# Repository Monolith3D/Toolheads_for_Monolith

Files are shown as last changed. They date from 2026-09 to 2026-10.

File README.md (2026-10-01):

# Toolheads for Monolith

Belt clamps, alignment helpers, and design guidance for adapting toolheads to the Monolith Gantry.

## Compatible toolheads

Each project provides its own files, build instructions, updates, and support.

- [A4T](https://github.com/Armchair-Heavy-Industries/A4T)
- [Angry Tool Head](https://github.com/Shamoon78/Angry_Tool_Head)
- [Archetype](https://github.com/Armchair-Heavy-Industries/Archetype)
- [Banantis](https://github.com/jakub874/Banantis)
- [Burninator](https://github.com/The-Duke-96/Burninator)
- [DK's Monolith Toolhead](https://github.com/Kizime123/DKs-Monolith-Toolhead)
- [Dreadnaught Toolhead](https://github.com/Thescarecow/Dreadnaught-Toolhead)
- [FiberStream Toolhead](https://www.printables.com/model/1219174-fiberstream-toolhead)
- [Gustav Railway Toolhead](https://github.com/RCI-Nicket/Gustav-Railway-Toolhead)
- [Microwaved Bowden Toolhead](https://github.com/micreathonn/Microwaved-Bowden-Toolhead)
- [RX Toolhead](https://makerworld.com/en/models/2816460-rx-toolhead-v5-using-bambu-h2s-a1-gear-hotend)
- [Sphinx Toolhead](https://github.com/riley-github/Sphinx-Toolhead)
- [Stormbreaker Toolhead](https://github.com/Gr33n5murf/Stormbreaker-Toolhead)
- [Takeoff Toolhead](https://github.com/Kizime123/Takeoff-Toolhead)
- [Trinity Toolhead](https://github.com/WV-design/Trinity-toolhead/)
- [Trinicorn SLM Toolhead](https://github.com/Martin-Ivanc/Trinicorn-Toolhead/)
- [UAP](https://www.printables.com/model/1353685-uap-v6)
- [Xol Toolhead](https://github.com/Armchair-Heavy-Industries/Xol-Toolhead)

## Belt clamps

The [Monolith belt clamp](Monolith_Belt_Clamp/) is a reference design for belt retention and easier adaptation to Monolith's belt path, available in milled and SLM variants.

### LDO milled belt clamp vendors

- [West3D](https://west3d.com/products/monolith-cnc-belt-clamp-by-ldo-motors) (US)
- [MyRigs](https://myrigs3d.com/fr/products/ldo-monolith-cnc-belt-clamp) (EU)
- [Zen3D](https://shop.zen3d.eu/monolith-cnc-belt-clamp) (EU)

### SLM belt clamp vendors

- [DK Supply](https://diodekingsupply.com/products/monolith-slm-belt-clip) (US)
- [3DKATTEN](https://3dkatten.se/products/monolith-slm-belt-clamp) (EU)
- [Pjotr3DShop](https://pjotr3dshop.com/products/monolith-slm-belt-clamp-aluminium) (EU)

## Belt alignment helpers

[Printable helpers](Belt_Alignment_Helpers/) and installation instructions for checking vertical belt spacing at the toolhead.

## Design guidelines

[Design guidelines](Design_Guidelines/) and integration CAD for adapting toolheads to Monolith.

## User Mods

Community-made additions and adaptations to help toolheads work with the Monolith Gantry.
Geometry and designs from other projects, including their derivatives, remain subject to their original licenses.

[Existing User Mods](UserMods/#existing-user-mods)

## Support

> [!NOTE]
> **If you have questions or want to stay more up-to-date with Monolith, consider joining the dedicated Discord server.**
>
> Join the Discord (https://discord.gg/monolith3d)
>
> **If you would like to see more of this and other projects in the future, consider supporting Monolith on Patreon.**
>
> Support Monolith on Patreon (https://www.patreon.com/monolith3d)

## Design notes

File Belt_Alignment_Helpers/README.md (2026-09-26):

# Belt Alignment Helpers

Check vertical belt spacing at the toolhead. Choose the helper that matches your belt width.

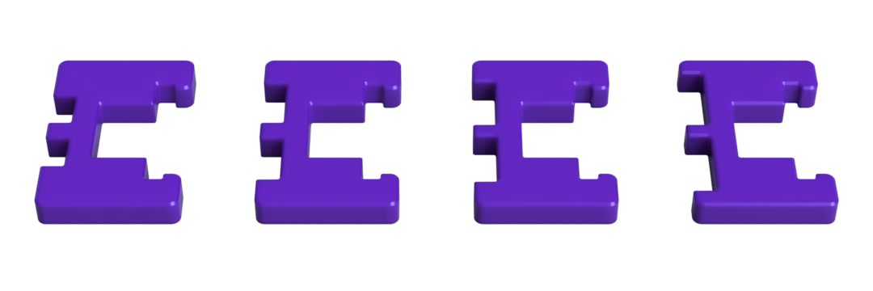
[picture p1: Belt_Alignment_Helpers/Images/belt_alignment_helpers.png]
Belt alignment helpers


STLs: [6 mm](STLs/6mm_belt_offset_helper.stl) · [9 mm](STLs/9mm_belt_offset_helper.stl) · [10 mm](STLs/10mm_belt_offset_helper.stl) · [12 mm](STLs/12mm_belt_offset_helper.stl)

[Download the STEP assembly](CAD/Belt_offset_helpers.step)

## How to use

Slide the helper between the X-rail and the belts, then rotate it into position to check the spacing. Check both sides of the toolhead.

Watch the installation video on YouTube (https://youtube.com/shorts/-358SNaWWXc)

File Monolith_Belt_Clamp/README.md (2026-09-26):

# Monolith Belt Clamp

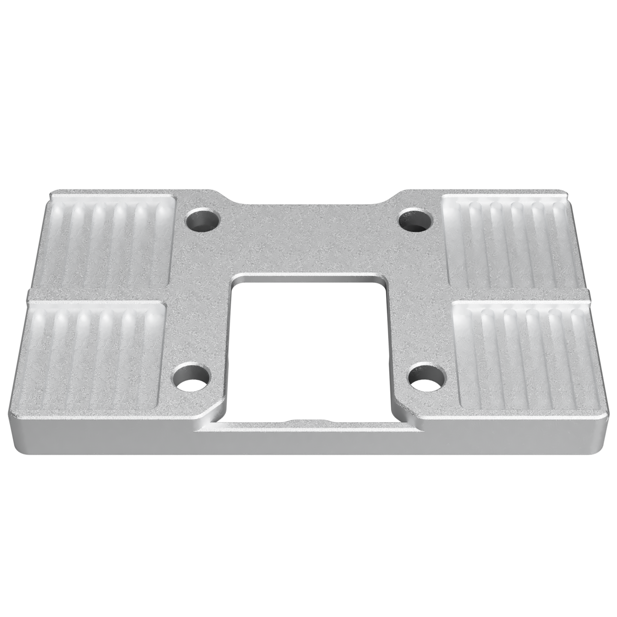
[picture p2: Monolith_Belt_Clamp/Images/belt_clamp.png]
Monolith milled belt clamp


A metal belt clamp for adapting toolheads to Monolith's flipped belt path, including toolheads with printed carriages.

The belt path runs one belt thickness from the MGN12H carriage, leaving room for a thin clamp around it.

## Design goals

- Single-piece, lightweight, and compact.
- At least six teeth engaged, as recommended by Gates.
- A straight loaded belt section without tight bends.
- Preserve standard 250, 300, and 350 mm X travels.
- Accommodate belts up to 12 mm wide without vertical restriction.
- Clip onto the carriage without screws during toolhead assembly.
- Keep excess belt outside, with easy slack removal using two partially tightened screws.

## Variants

Both versions have the same fit and function and are interchangeable in existing toolhead designs. Prefer milled when getting a new clamp, but there's no reason to replace an SLM clap that already works well.

- [Milled](Milled/): Improved version with more consistent manufacturing. Recommended over SLM.
- [SLM](SLM/): Quality varies by supplier and batch, and the geometry makes manufacturing defects difficult to correct through post-processing.

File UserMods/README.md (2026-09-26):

# User Mods

Community-made additions and adaptations to help toolheads work with the Monolith Gantry.

Geometry and designs from other projects, including their derivatives, remain subject to their original licenses.

Use the folder structure `username/usermod_name` for new user mods.

## Existing User Mods

No user mods have been added yet. The rows below are examples for new submissions.

| Mod | Author | What it does |
| --- | --- | --- |
| usermod_name | username | Briefly describe what the mod adds, adapts, or changes. |
|  | your name here :) |  |

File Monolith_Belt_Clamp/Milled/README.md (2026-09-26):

# Milled Belt Clamp

The milled belt clamp, co-developed with **@dderg**.

## CAD

[STEP file](CAD/Monolith_Milled_Belt_Clamp.step)

## LDO milled belt clamp vendors

- [West3D](https://west3d.com/products/monolith-cnc-belt-clamp-by-ldo-motors) (US)
- [MyRigs](https://myrigs3d.com/fr/products/ldo-monolith-cnc-belt-clamp) (EU)
- [Zen3D](https://shop.zen3d.eu/monolith-cnc-belt-clamp) (EU)

The LDO version is black-anodized aluminum.

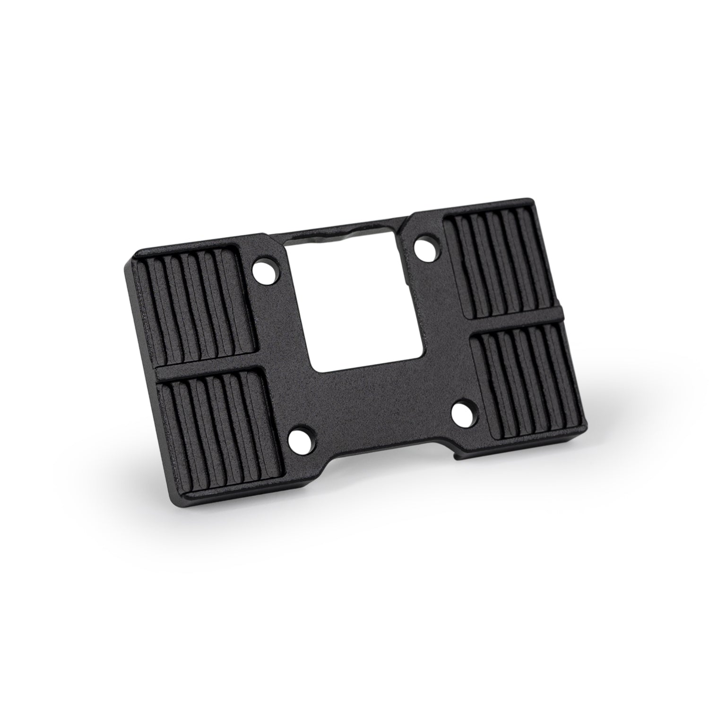
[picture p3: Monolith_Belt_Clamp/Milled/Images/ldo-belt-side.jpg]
LDO milled belt clamp


## Development

Developed from the A-type SLM version. Early prototypes made by @dderg introduced a heatbreak cutout, a flat front, and longer AirTAC carriage compatibility.

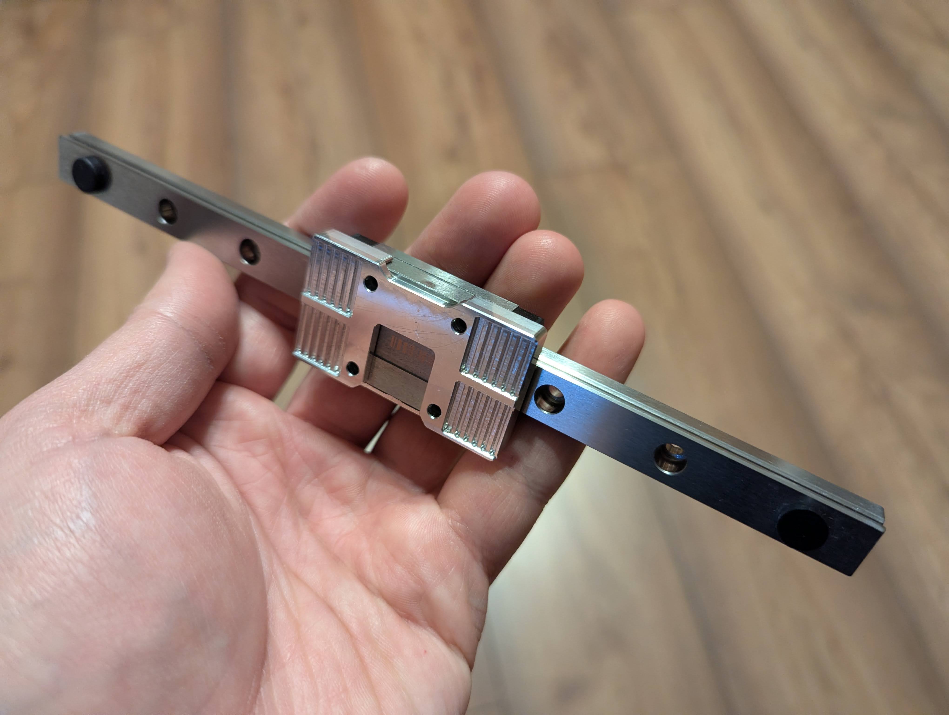
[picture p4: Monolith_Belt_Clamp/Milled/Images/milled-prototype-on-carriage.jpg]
Earlier milled prototype on a carriage


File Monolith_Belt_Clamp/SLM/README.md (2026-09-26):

# SLM Belt Clamp

The SLM metal belt clamp for Monolith's flipped belt path.
## CAD

- [STEP file](CAD/Monolith_SLM_Belt_Clamp.step)
- [STL file](STL/Monolith_SLM_Belt_Clamp.stl)

## SLM belt clamp vendors

- [DK Supply](https://diodekingsupply.com/products/monolith-slm-belt-clip) (US)
- [3DKATTEN](https://3dkatten.se/products/monolith-slm-belt-clamp) (EU)
- [Pjotr3DShop](https://pjotr3dshop.com/products/monolith-slm-belt-clamp-aluminium) (EU)

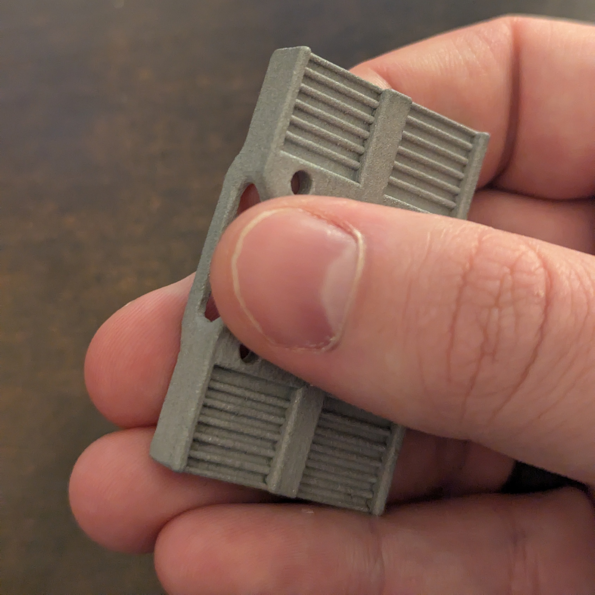
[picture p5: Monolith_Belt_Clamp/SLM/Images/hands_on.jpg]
SLM belt clamp


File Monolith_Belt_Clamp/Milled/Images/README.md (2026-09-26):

# LDO Belt Clamp Photos

| Image | Image |
| --- | --- |
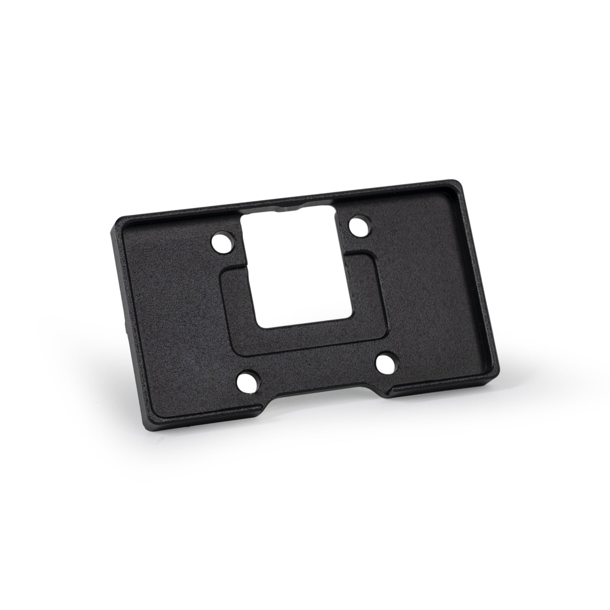
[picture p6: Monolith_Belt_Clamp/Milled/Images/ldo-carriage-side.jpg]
LDO belt clamp carriage-facing side
| [LDO belt clamp belt-facing side<br>Belt-facing side](ldo-belt-side.jpg) | [<br>Carriage-facing side](ldo-carriage-side.jpg) |
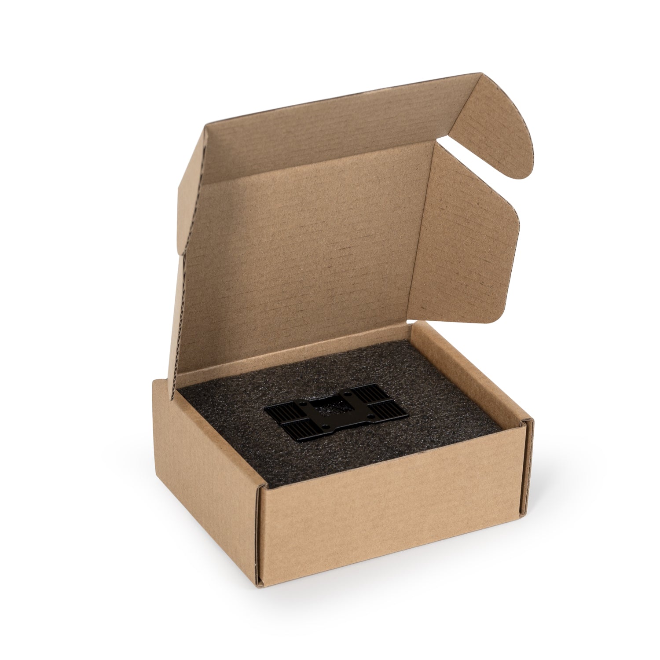
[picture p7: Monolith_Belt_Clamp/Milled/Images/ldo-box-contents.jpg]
LDO belt clamp in its open box
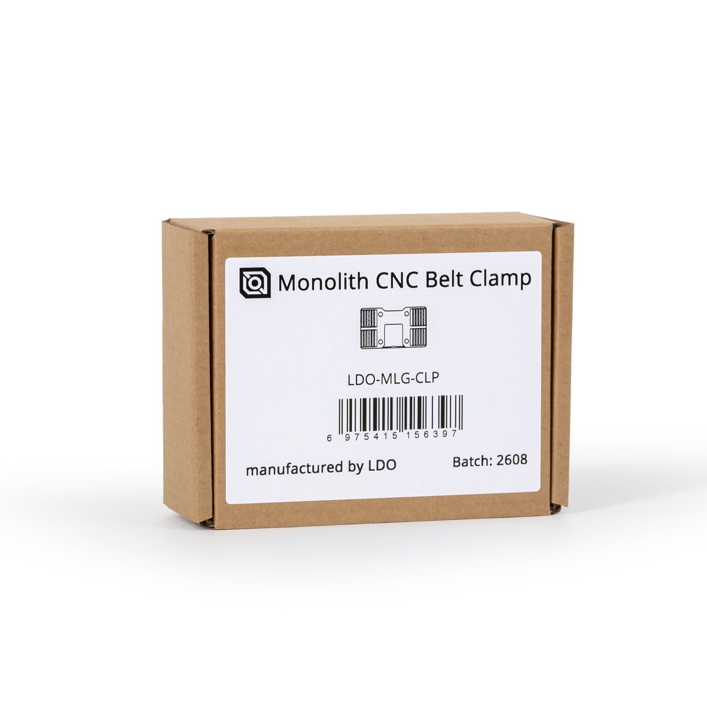
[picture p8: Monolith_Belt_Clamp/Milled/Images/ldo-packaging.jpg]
LDO belt clamp package label
| [<br>Box contents](ldo-box-contents.jpg) | [<br>Packaging](ldo-packaging.jpg) |

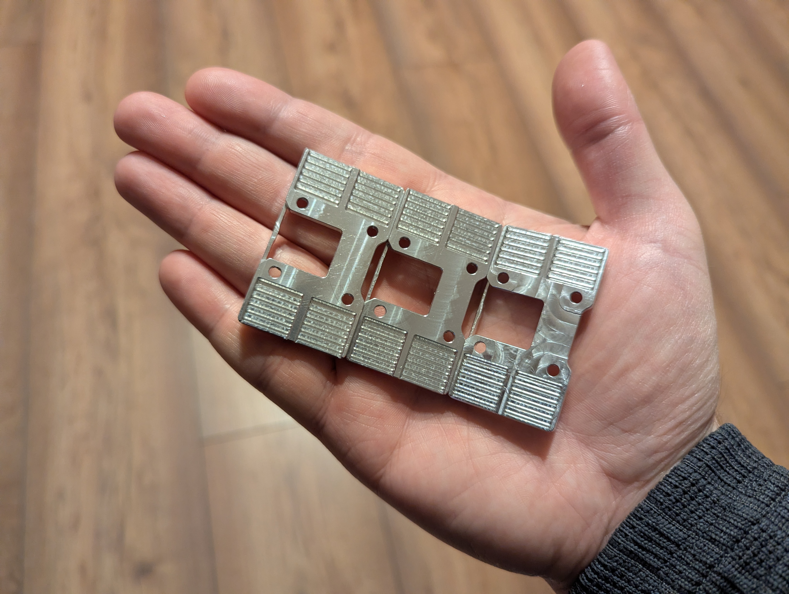
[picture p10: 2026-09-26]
Monolith_Belt_Clamp/Milled/Images/milled-prototype-iterations.jpg

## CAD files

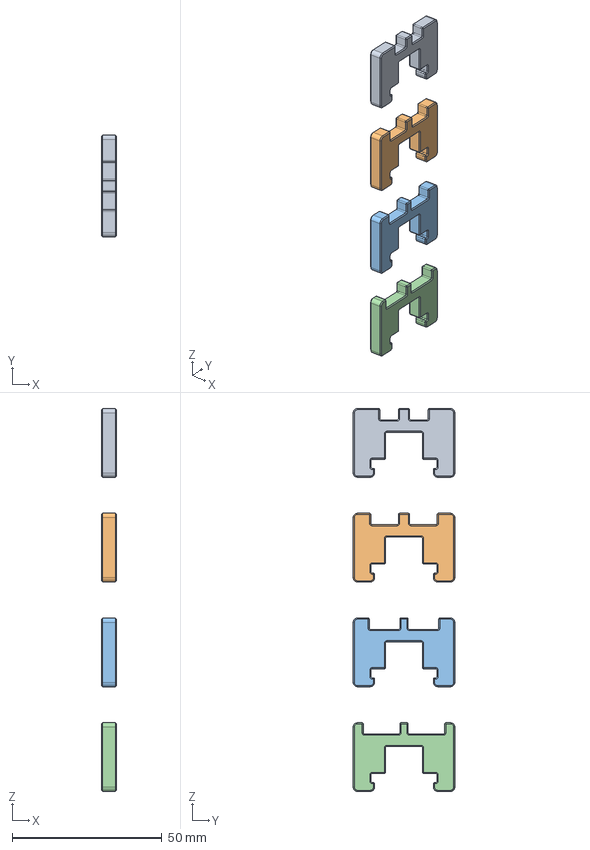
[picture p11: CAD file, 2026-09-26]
Belt_Alignment_Helpers/CAD/Belt_offset_helpers.step
5.00 x 34.0 x 128.0 mm
6mm_belt_offset_helper
9mm_belt_offset_helper
10mm_belt_offset_helper
12mm_belt_offset_helper

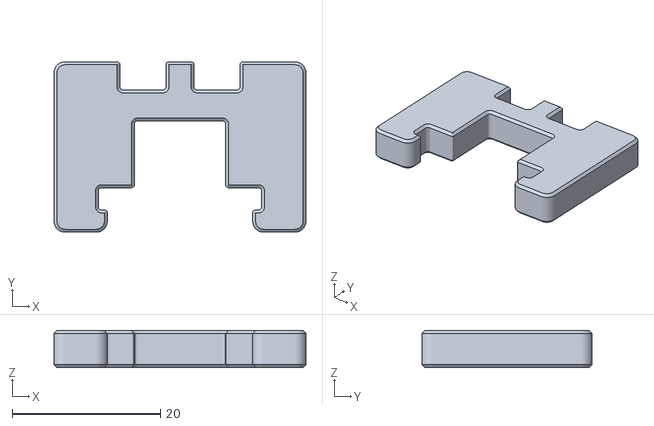
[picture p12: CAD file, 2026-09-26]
Belt_Alignment_Helpers/STLs/6mm_belt_offset_helper.stl
34.0 x 23.0 x 5.00

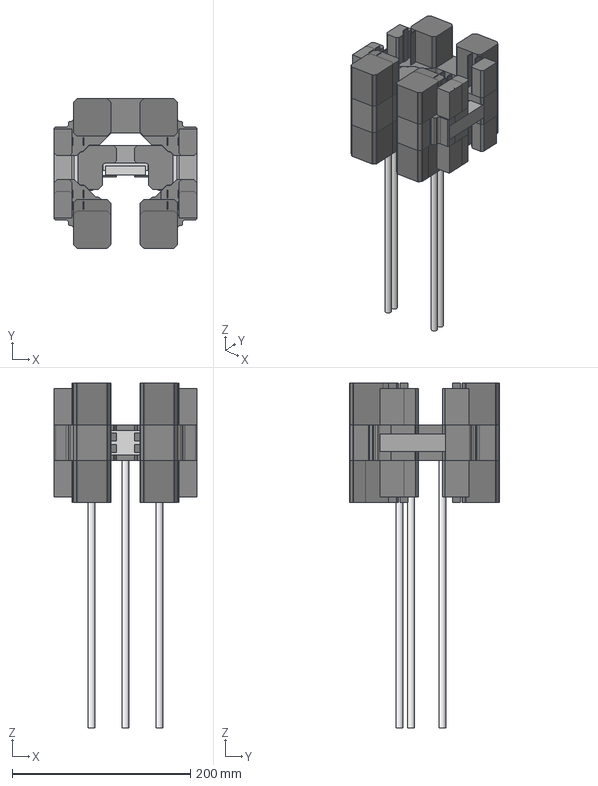
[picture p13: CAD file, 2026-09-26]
Design_Guidelines/CAD/Toolhead_Integration.step
160.0 x 168.0 x 387.0 mm

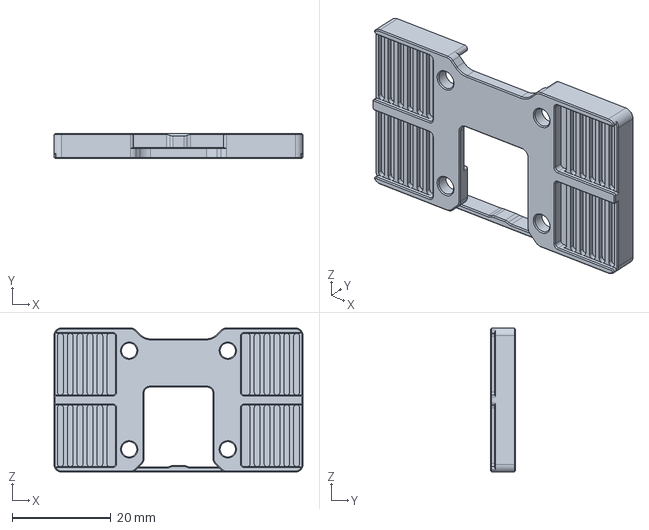
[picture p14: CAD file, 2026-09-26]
Monolith_Belt_Clamp/Milled/CAD/Monolith_Milled_Belt_Clamp.step
50.5 x 5.00 x 29.2 mm

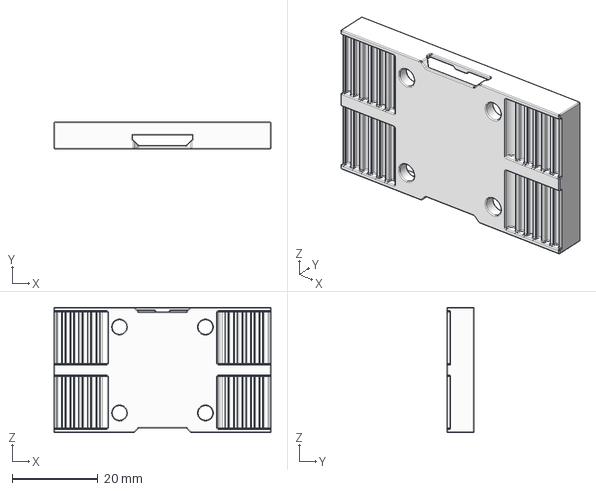
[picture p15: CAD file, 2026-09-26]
Monolith_Belt_Clamp/SLM/CAD/Monolith_SLM_Belt_Clamp.step
50.5 x 6.24 x 29.2 mm

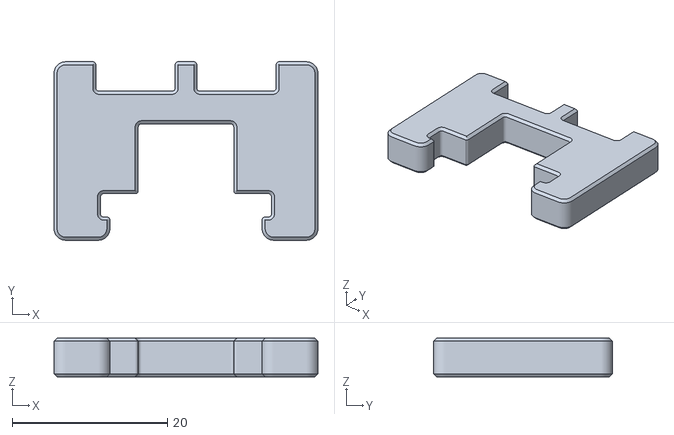
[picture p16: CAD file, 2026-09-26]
Belt_Alignment_Helpers/STLs/10mm_belt_offset_helper.stl
34.0 x 23.0 x 5.00

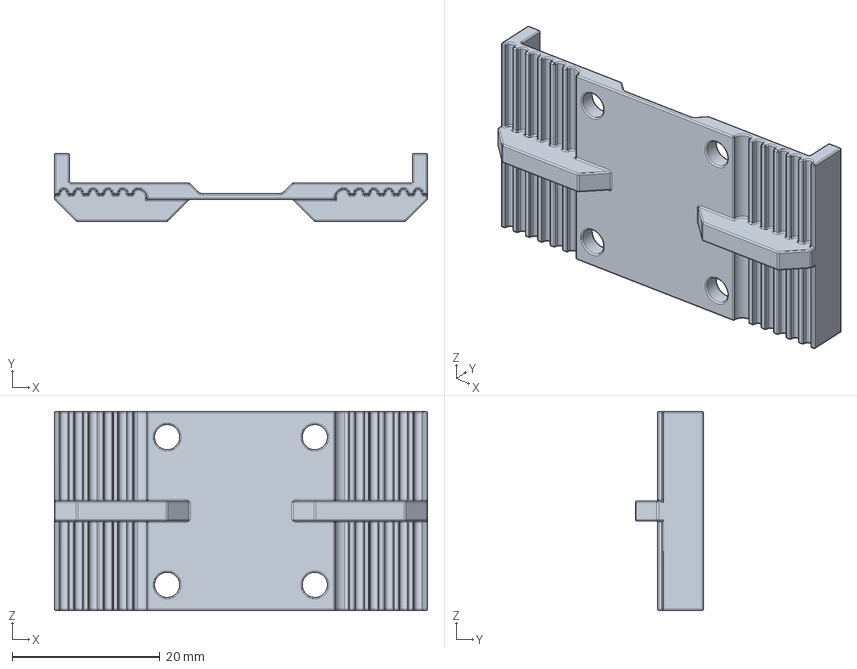
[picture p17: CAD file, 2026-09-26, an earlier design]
Monolith_Belt_Clamp/SLM/Legacy/Monolith_SLM_Belt_Clamp_Type_B.step
50.5 x 9.24 x 27.0 mm

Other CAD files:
Belt_Alignment_Helpers/STLs/9mm_belt_offset_helper.stl
Belt_Alignment_Helpers/STLs/12mm_belt_offset_helper.stl
Monolith_Belt_Clamp/SLM/STL/Monolith_SLM_Belt_Clamp.stl

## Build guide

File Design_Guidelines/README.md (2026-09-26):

# Design guidelines

General design criteria, independent of the third-party toolhead list.

## Toolhead integration CAD

[Toolhead integration STEP](CAD/Toolhead_Integration.step): Simplified gantry geometry for checking toolhead clearance.

Includes AWD full Y travel, AWD FT-FT without Y overtravel, and 2WD full Y travel. Show one scenario at a time.

## Belt retention

- Match Monolith's flipped belt orientation, belt spacing, and selected belt width.
- Follow Gates' tooth-engagement and minimum bend-radius guidance.
- Belt retention and the toolhead must support the target belt tension. Otherwise reduce tension to the limit of the weakest motion-system or frame component.
- Retention geometry, worst to best:
    - sharp-edged wrap, few engaged teeth
    - rounded-pin wrap, tight bend and few engaged teeth
    - sufficient engagement, tight loaded-path bend
    - straight clamp, at least six engaged teeth and no loaded-path bend on the toolhead (Monolith target).

## Stiffness and center of mass

- Evaluate the complete printer/toolhead system: total mass, center of mass, carriage stiffness, and the hotend and extruder mounts, including their attachment to the carriage.
- A metal carriage can reduce carriage deflection under belt tension, but it does not remove flexibility in printed hotend and extruder mounts.
- Treat the X-rail as part of the toolhead stiffness. Z2 / the highest available preload is recommended, especially with AWD, high belt tension, heavier toolheads, or toolheads with poor center of mass. Other preload classes can work.

## Clearance and endstops

- X travel and AWD front clearance depend on the toolhead.
- Check cable clearance throughout the full travel range.
- Physical X and Y endstop switches and sensorless homing are supported.
- The gantry-side [X-endstop housing](https://github.com/Monolith3D/Monolith_Gantry/blob/main/STLs/X_endstop_housing.stl) mounts to the Y extrusion because toolheads, carriages, and XY-joints do not share one universal toolhead-mounted switch position. Home Y before X when using it.
- The [Y-endstop housing](https://github.com/Monolith3D/Monolith_Gantry/blob/main/STLs/Y_endstop_housing.stl) mounts on the rear extrusion between the rear mounts and is triggered by the X-beam.

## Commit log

2026-09-26 Initial upload
    [10mm_belt_offset_helper.stl, 12mm_belt_offset_helper.stl, 6mm_belt_offset_helper.stl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]
2026-09-26 Added legacy clamp
    [Monolith_SLM_Belt_Clamp_Type_B.step]
2026-09-26 Expand rail, clearance, and endstop guidance
2026-09-28 Add Microwaved Bowden Toolhead link to README
